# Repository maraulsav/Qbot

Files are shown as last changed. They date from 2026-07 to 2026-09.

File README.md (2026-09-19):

# Qbot-the-self-balancing-robot
Qbot is a self balancing robot that integrate PID mechanism to balances.

The Final Design:


## Key Features
* **ESP32 DevKit C** is the main microcontroller allowing wifi connection for remote controller
* **OLED display 128 x 64 px** for displaying the faces and current state of emotion
* **15 V Lipo Battery** to give power supply
* **MPU 6050** Act as gyroscope and accelerator to measure the degree of robot imbalance
* **Buzzer** to make sounds
* **Button** to regulate the power supply from battery
* **DC DC Buck Converter** to regulate the voltage supply
* **TMC2208 Motor Driver** To help control the wheel motion

## Printed Circuit Board (PCB)
Below is the schematic that I used



Below is the PCB design



And here how to connect the PCB to other component of the robot



**PCB Footprint List**
* 10uF capacitor: Capacitor_THT:CP_Radial_D5.0mm_P2.00mm
* 100uF capacitor: Capacitor_THT:CP_Radial_D6.3mm_P2.50mm
* Zener Diode: Diode_THT:D_DO-35_SOD27_P10.16mm_Horizontal
* LED: LED_THT:LED_D3.0mm
* Mounting Hole: MountingHole:MountingHole_3.2mm_M3
* Connector: Connector_PinHeader_2.54mm:PinHeader_1x04_P2.54mm_Vertical
* Connector 1x02: Connector_AMASS:AMASS_XT30U-M_1x02_P5.0mm_Vertical
* GY521 (MPU6050): GY-521:MODULE_GY-521
* ESP32 DevKit C: Library:MODULE_ESP32-DEVKITC
* TMC2208_SILENTSTEPSTICK:MODULE_TMC2208_SILENTSTEPSTICK

## 3D Design
Note that I would be using 12 cm wheel

Front Side



Right Side



Back Side



## Codes
Code Sample:



## BOM
| Component | Qty | Total (IDR) | Total (USD) | Link |
|---|----:|---:|---:|---|
| Stepper Motor 17HS4401S | 2 | - | $19.08 |[Link](https://www.aliexpress.com/item/1005008098470320.html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) |
| Printed Circuit Board (PCB) | 1 | — | $3.50 | — |
| 2 x Metal 1.9 Beadlock Wheel Rim | 1 | - | $11.12 | [Link](https://www.aliexpress.com/item/1005007014668118.html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) |
| 4pcs 1.9" Wheel Tires (120mm) | 1 | 85,000 | $4.73 | [Link](https://www.aliexpress.com/item/1005005554788142.html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) |
| ESP32-C3 DevKit | 1 | 85,000 | $4.73 | [Link](https://www.tokopedia.com/temins/esp32-nodemcu-esp-32-esp32s-32s-wifi-module-devkit-dev-38-pin-1729797014153692567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) |
| GY-521 MPU-6050 | 1 | 29,500 | $1.64 | [Link](https://www.tokopedia.com/khurs-iot/gy-521-mpu-6050-3-axis-accelerometer-gyroscope-arduino-raspberry-pi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) |
| TMC2208 Motor Driver | 2 | - | $5,82 | [Link](https://www.aliexpress.com/item/1005010480173953.html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) |
| LiPo Battery (11.1V) | 1 | 169,200 | $9.42 | [Link](https://www.tokopedia.com/rin-toys/baterai-lipo-11-1-volt-3s-batre-lithium-polymer-for-wgg-mobil-rc-1734386815592072921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) |
| LiPo Battery Charger | 1 | 65,000 | $3.61 | [Link](https://www.tokopedia.com/rin-toys/charger-baterai-balance-charger-for-2s-3s-7-4v-11-1v-lithium-lipo-battery-1731018524016871129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) |
| Neodymium Magnet | 1 | 20,000 | $1.11 | [Link](https://www.tokopedia.com/tokodstore/magnet-kuat-neodymium-bulat-diy-5-3mm-50pcs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) |
| OLED Display | 2 | 73,000 | $4.09 | [Link](https://www.tokopedia.com/cncstorebandung/oled-display-0-96-inch-i2c-128-64-layar-oled-putih-biru-kuning-biru-untuk-arduino-esp32-dan-proyek-diy-1733644920011851326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)|
| Push Button | 1 | 15,000 | $0.83 | [Link](https://www.tokopedia.com/arduinonano/r16-503bd-4-pin-16mm-push-on-non-locked-button-switch-250v-light-merah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) |
| Jumper Wire (15 cm, 40 pcs) | 1 pack | 23,000 | $1.28 | [Link](https://www.tokopedia.com/arduinonano/kabel-jumper-40p-cable-dupont-pelangi-15cm-40pin-header-cable-pin-rainbow-15-cm-1729801397622441069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) |
| Header Pin | 1 pack | 14,000 | $0.78 | [Link](https://www.tokopedia.com/arduinonano/1x40-pin-2-0mm-male-single-row-header-strip-40-40p-pit-2mm-tulang-ikan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) |
| Heatsink | 2 | 4,656 | $0.26 | [Link](https://www.tokopedia.com/rajacell/heatsink-aluminium-pendingin-14x14x6mm-dengan-3m-thermal-tape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) |
| Heat-Set Inserts | 1 | 252,200 | $14.02 | [Link](https://www.tokopedia.com/smbility/insert-nut-kuningan-hot-500pcs-hot-melt-nutinsert-thread-knurled-spiral-brass-nut-insert-1730606018733835796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) |
| Nut Set | 1 | 131,000 | $7.28 | [Link](https://www.tokopedia.com/fyn-by-finedego/baut-set-m3-m4-m5-m6-600-pcs-hex-ring-mur-screw-bolt-nuts-assortment-kit-stainless-steel-l-bulat-40mm-30mm-20mm-10mm-16mm-1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) |
| 10 µF Capacitor | 1 | 20,400 | $1.14 | [Link](https://www.tokopedia.com/lektropedia/elco-10uf-450v-kapasitor-10-uf-mikro-450-v-volt-elko-450volt-capasitor-1-49-pcs-ed5a8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) |
| 100 µF Capacitor | 3 | 24,900 | $1.16 | [Link](https://www.tokopedia.com/lektropedia/elco-100uf-450v-kapasitor-100-uf-mikro-450-v-volt-elko-450volt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) |
| Zener Diode | 1 | 10,000 | $0.56 | [Link](https://www.tokopedia.com/arduinonano/dioda-zener-1w-3v6-3-6v-1n4729a-in4729a-1n4729-in4729-diode-do-41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) |
| LED | 1 | 1,250 | $0.07 | [Link](https://www.tokopedia.com/arduinonano/led-blink-red-5mm-diode-super-bright-led-kedip-merah-led-5mm-kedip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) |
| 1 kΩ Resistor | 1 | 15,000 | $0.83 | [Link](https://www.tokopedia.com/arduinonano/10pcs-resistor-1k-1-kilo-k-ohm-1-4-watt-0-25-metal-film-tolerance-1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) |
| LM2596S  DC to DC Buck Converter | 1 | 34,200 | $1,92 | [Link](https://www.tokopedia.com/tokoasia-jkt/lm2596s-buck-converter-dc-dc-step-down-voltage-regulator-36v-24v-12v-to-5v-2a-volt-digital-display-2596s-1730718483558664143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) |
| Active Buzzer | 1 | 5,000 | $0.28 | [Link](https://www.tokopedia.com/azzamarduino/buzzer-speaker-aktif-active-dc-3v-24v-sfm-27-3cm-input-3v-5v-12v-bunyi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) |
| XT30 Amass Connector | 1 | 8,500 | $0.47 | [Link](https://www.tokopedia.com/arduinonano/amass-connector-plug-xt30u-amass-xt-30-u-konektor-for-power-1732555087363605613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) |
| 3D Printed Parts | — | — | $9.00 | — |
| **Total** | | **IDR2.049.638** | **USD 115.07** | |

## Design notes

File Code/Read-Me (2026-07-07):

Here contain the code of my Qbot
I use the header and cpp formatting so that the code did not jungle up in one big file. 
If you wanted to use or modify, Download this folder as a zip the open it.
Also download the file that allow MPU6050 to the ESP32C3 in this 
link https://github.com/jrowberg/i2cdevlib (click arduino then MPU6050)

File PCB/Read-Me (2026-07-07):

Here lays the schematic and the pcb layout of my Qbot. 
If you wanted to modify it you can download the .pro file then open it on KiCad.

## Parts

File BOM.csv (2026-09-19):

Name | Qty | Total (IDR) | Total (USD) | Link
Stepper Motor 17HS4401S | 2 |  | 19,08 | https://www.aliexpress.com/item/1005008098470320.html?curPageLogUid=qqeqjQQUr7C6
ESP32C3 DevKit | 1 | 85000 | 4,73 | https://www.tokopedia.com/temins/esp32-nodemcu-esp-32-esp32s-32s-wifi-module-devkit-dev-38-pin-1729797014153692567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
GY-521 MPU-6050 | 1 | 29500 | 1,64 | https://www.tokopedia.com/khurs-iot/gy-521-mpu-6050-3-axis-accelerometer-gyroscope-arduino-raspberry-pi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
LM2596S DC to DC Buck Converter | 1 | 34200 | 1,92 | https://www.tokopedia.com/tokoasia-jkt/lm2596s-buck-converter-dc-dc-step-down-voltage-regulator-36v-24v-12v-to-5v-2a-volt-digital-display-2596s-17307184835586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
Printed Circuit board | 1 |  | 3,5 | JLCPCB
TMC2208 Motor Driver | 2 |  | 5,82 | https://www.aliexpress.com/item/1005010480173953.html?curPageLogUid=mdaYc0tmK80y
Lipobattery 11.1V | 1 | 169200 | 9,42 | https://www.tokopedia.com/rin-toys/baterai-lipo-11-1-volt-3s-batre-lithium-polymer-for-wgg-mobil-rc-1734386815592072921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
LIpobattery charger | 1 | 65000 | 3,61 | https://www.tokopedia.com/rin-toys/charger-baterai-balance-charger-for-2s-3s-7-4v-11-1v-lithium-lipo-battery-1731018524016871129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
Magnet | 1 | 20000 | 1,11 | https://www.tokopedia.com/tokodstore/magnet-kuat-neodymium-bulat-diy-5-3mm-50pcs?t_id=1783211974588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
OLED Display | 2 | 73000 | 4,09 | https://www.tokopedia.com/cncstorebandung/oled-display-0-96-inch-i2c-128-64-layar-oled-putih-biru-kuning-biru-untuk-arduino-esp32-dan-proyek-diy-1733644920011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
Button | 1 | 15000 | 0,83 | https://www.tokopedia.com/arduinonano/r16-503bd-4-pin-16mm-push-on-non-locked-button-switch-250v-light-merah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
Jumper Wire 15 cm | 1 pack | 23000 | 1,28 | https://www.tokopedia.com/arduinonano/kabel-jumper-40p-cable-dupont-pelangi-15cm-40pin-header-cable-pin-rainbow-15-cm-1729801397622441069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
Header Pin | 1 pack | 14000 | 0,78 | https://www.tokopedia.com/arduinonano/1x40-pin-2-0mm-male-single-row-header-strip-40-40p-pit-2mm-tulang-ikan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
Heatsink | 2 | 4656 | 0,26 | https://www.tokopedia.com/rajacell/heatsink-aluminium-pendingin-14x14x6mm-dengan-3m-thermal-tape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
Heatset insert | 1 | 252200 | 14,02 | https://www.tokopedia.com/smbility/insert-nut-kuningan-hot-500pcs-hot-melt-nutinsert-thread-knurled-spiral-brass-nut-insert-1730606018733835796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
Nut set | 1 | 131000 | 7,28 | https://www.tokopedia.com/fyn-by-finedego/baut-set-m3-m4-m5-m6-600-pcs-hex-ring-mur-screw-bolt-nuts-assortment-kit-stainless-steel-l-bulat-40mm-30mm-20mm-10mm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
10 uF capacitor | 1 | 20400 | 1,14 | https://www.tokopedia.com/lektropedia/elco-10uf-450v-kapasitor-10-uf-mikro-450-v-volt-elko-450volt-capasitor-1-49-pcs-ed5a8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
100 uF capcitor (3.5 cm height) | 3 | 24900 | 1,16 | https://www.tokopedia.com/lektropedia/elco-100uf-450v-kapasitor-100-uf-mikro-450-v-volt-elko-450volt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
Zener diode | 1 | 10000 | 0,56 | https://www.tokopedia.com/arduinonano/dioda-zener-1w-3v6-3-6v-1n4729a-in4729a-1n4729-in4729-diode-do-41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
LED | 1 | 1250 | 0,07 | https://www.tokopedia.com/arduinonano/led-blink-red-5mm-diode-super-bright-led-kedip-merah-led-5mm-kedip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
Resistor | 1 | 15000 | 0,83 | https://www.tokopedia.com/arduinonano/10pcs-resistor-1k-1-kilo-k-ohm-1-4-watt-0-25-metal-film-tolerance-1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
Buzzer | 1 | 5000 | 0,28 | https://www.tokopedia.com/azzamarduino/buzzer-speaker-aktif-active-dc-3v-24v-sfm-27-3cm-input-3v-5v-12v-bunyi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
Amass Connector | 1 | 8500 | 0,47 | https://www.tokopedia.com/arduinonano/amass-connector-plug-xt30u-amass-xt-30-u-konektor-for-power-1732555087363605613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
4pcs 1.9" Wheel Tires (120mm) |  | - | 11,07 | https://www.aliexpress.com/item/1005005554788142.html?scm_id=1007.40050.354490.0&scm-url=1007.40050.354490.0
Metal 1.9 Beadlock Wheel Rim |  | - | 11,12 | https://www.aliexpress.com/item/1005007014668118.html?scm_id=1007.40050.354490.0&scm-url=1007.40050.354490.0
3D Print |  |  | 9 | Printing Legion
 | SUM | 2.098.799,74 | 115,07

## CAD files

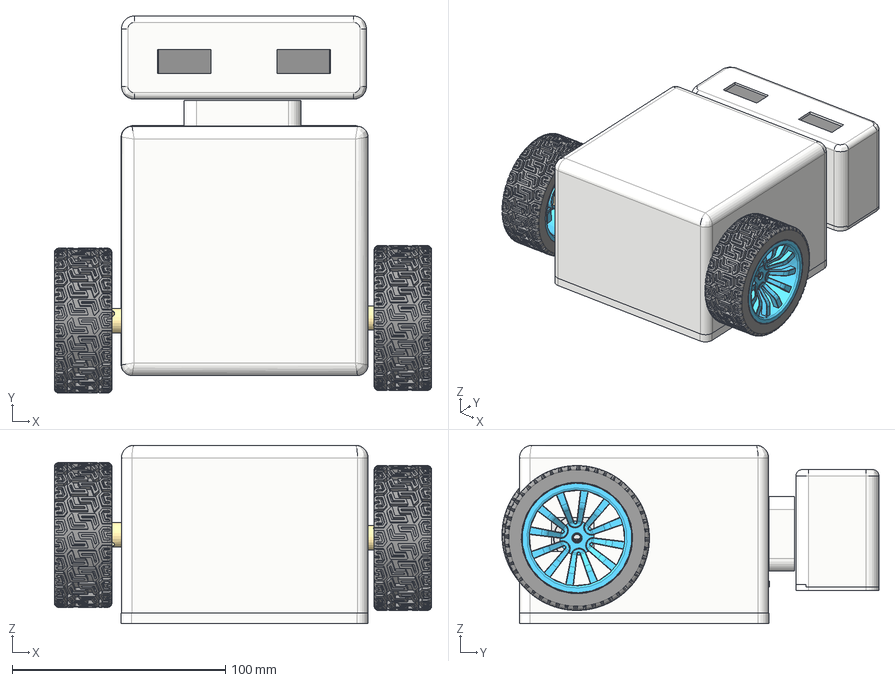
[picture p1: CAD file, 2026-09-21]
3D Print/Qbot (Assembly).step
177.1 x 177.0 x 83.8 mm

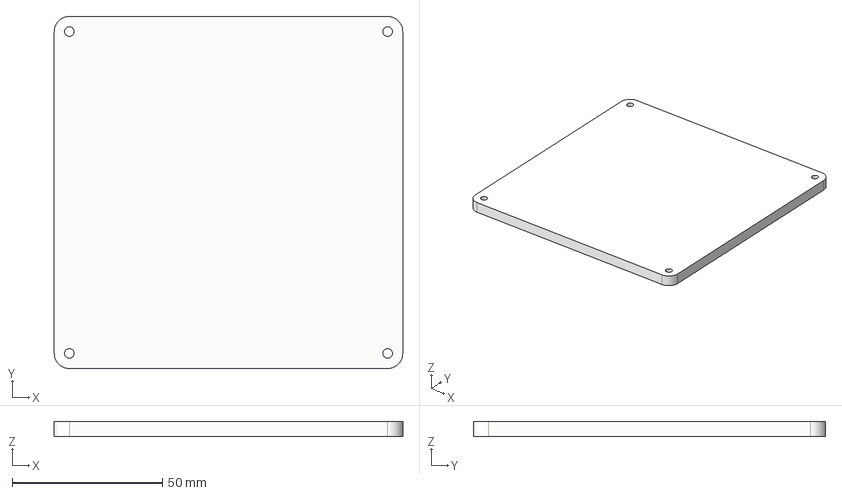
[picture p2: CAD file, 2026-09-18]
3D Print/Body Door.step
115.8 x 117.0 x 5.00 mm

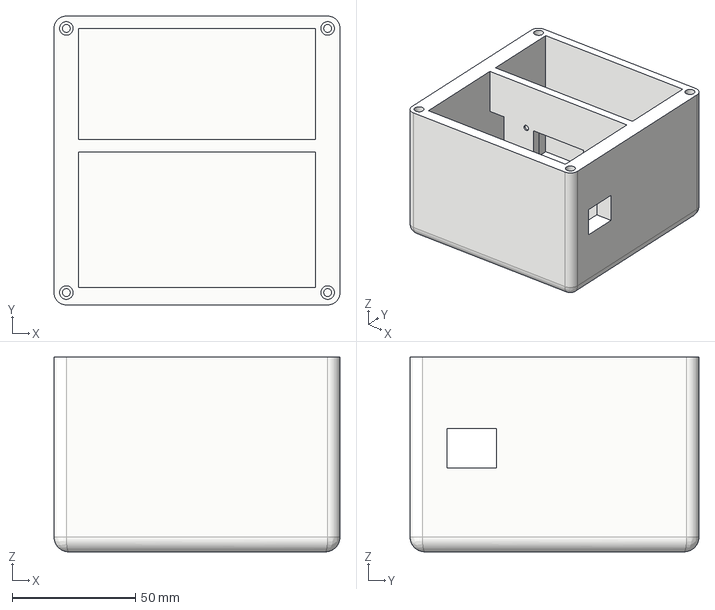
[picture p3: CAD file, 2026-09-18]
3D Print/Body#2.step
115.8 x 117.0 x 78.8 mm

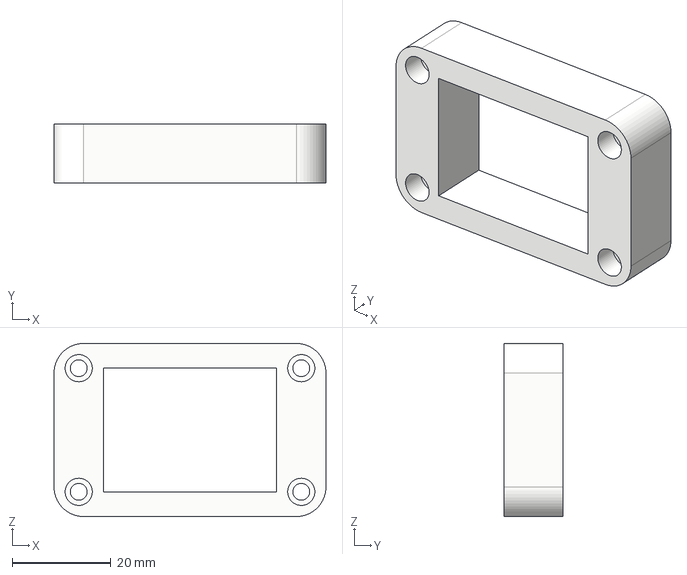
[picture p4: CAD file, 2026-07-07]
3D Print/Neck.step
55.0 x 12.0 x 35.0 mm

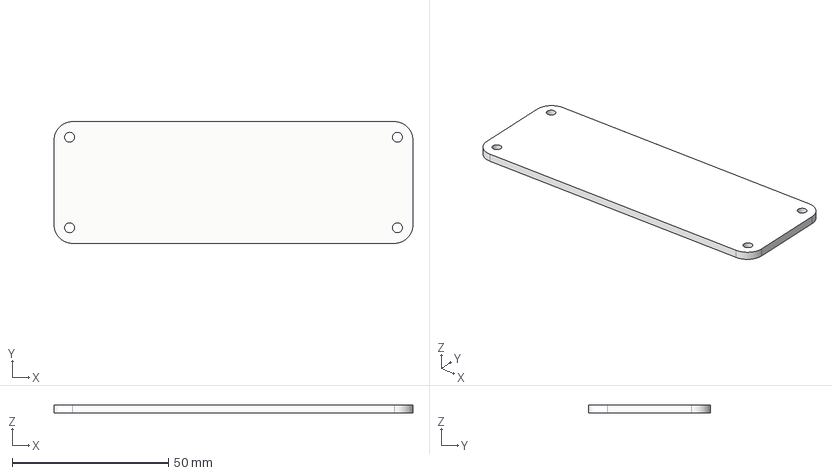
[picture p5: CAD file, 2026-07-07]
3D Print/Head Door.step
115.0 x 39.0 x 2.70 mm

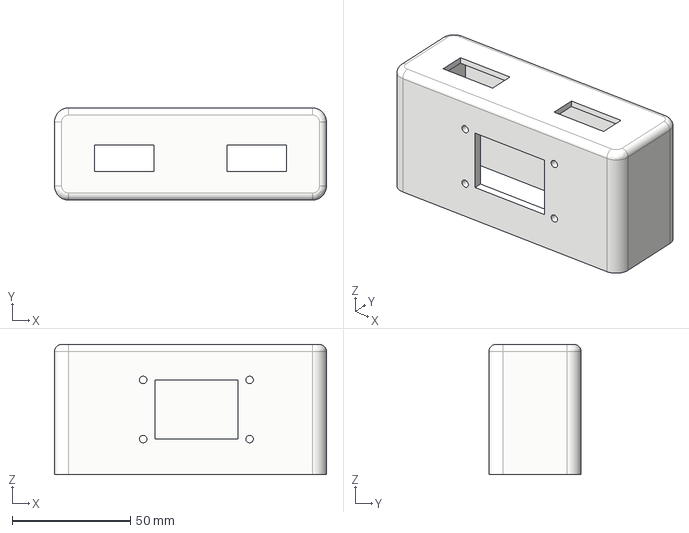
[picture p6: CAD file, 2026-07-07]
3D Print/Qbot Head.step
115.0 x 39.0 x 55.0 mm

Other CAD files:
3D Print/Body Door.f3d
3D Print/Body#2.f3d
3D Print/Head Door.f3d
3D Print/Neck.f3d
3D Print/Qbot Head.f3d

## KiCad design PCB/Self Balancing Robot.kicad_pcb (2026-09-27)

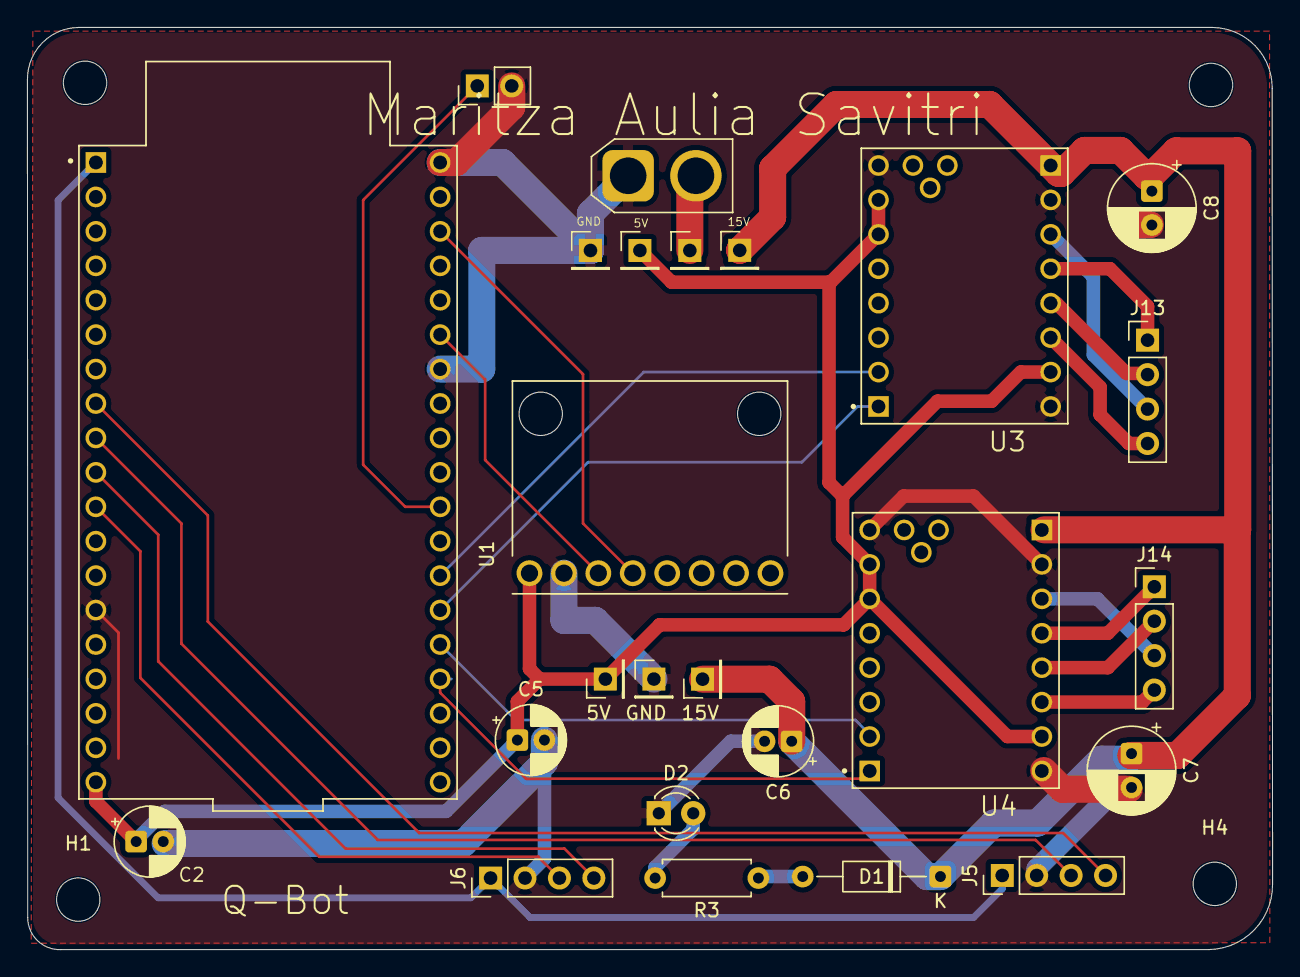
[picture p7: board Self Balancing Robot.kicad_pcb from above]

Board: 2 copper layers, 91.9 x 68.0 mm, 29 parts (0 on the bottom side), 26 nets.

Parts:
5V, 15V: Conn_01x01; PinHeader_1x01_P2.54mm_Vertical
C2, C5, C6: 10uF; CP_Radial_D5.0mm_P2.00mm
C7, C8: 100uF; CP_Radial_D6.3mm_P2.50mm
D1: D_Zener; D_DO-35_SOD27_P10.16mm_Horizontal
D2: LED; LED_D3.0mm
GND: Conn_01x01; PinHeader_1x01_P2.54mm_Vertical
H1, H2, H3, H4: MountingHole; MountingHole_3.2mm_M3
J3: Conn_01x02; AMASS_XT30U-M_1x02_P5.0mm_Vertical
J4: -SW; PinHeader_1x01_P2.54mm_Vertical
J5, J6, J13, J14: Conn_01x04; PinHeader_1x04_P2.54mm_Vertical
J7: +SW; PinHeader_1x01_P2.54mm_Vertical
J8: +SWLED; PinHeader_1x01_P2.54mm_Vertical
J9: -SWLED; PinHeader_1x01_P2.54mm_Vertical
J10: Conn_01x02; PinHeader_1x02_P2.54mm_Vertical
R3: 1k; R_Axial_DIN0207_L6.3mm_D2.5mm_P7.62mm_Horizontal
U1: GY-521; MODULE_GY-521
U2: ESP32-DEVKITC; MODULE_ESP32-DEVKITC
U3, U4: TMC2208_SILENTSTEPSTICK; MODULE_TMC2208_SILENTSTEPSTICK

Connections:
+3V3: J5.1, J6.1, U2.1 (3V3)
+5V: 5V.1 (Pin_1_1), C2.1, C5.1, J8.1 (Pin_1_1), U1.VCC, U2.19 (EXT_5V), U3.JP1_6 (MS2), U3.JP1_7 (MS1), U3.JP2_7 (VIO), U4.JP1_6 (MS2), U4.JP1_7 (MS1), U4.JP2_7 (VIO)
+15V: 15V.1 (Pin_1_1), C6.1, C7.1, C8.1, D1.1 (K), J7.1 (Pin_1_1), U3.JP2_1 (VM), U4.JP2_1 (VM)
/IO17: J10.1, U2.28 (IO17)
/MDDIR1: U2.25 (IO0), U3.JP1_1 (DIR)
/MDDIR2: U2.23 (IO15), U4.JP1_1 (DIR)
/MDSTEP1: U2.26 (IO4), U3.JP1_2 (STEP)
/MDSTEP2: U2.24 (IO2), U4.JP1_2 (STEP)
/SCL: U1.SDA, U2.36 (IO22)
/SCL1: J5.3, U2.9 (IO25)
/SCL2: J6.3, U2.11 (IO27)
/SDA: U1.SCL, U2.33 (IO21)
/SDA1: J5.4, U2.8 (IO33)
/SDA2: J6.4, U2.10 (IO26)
GND: C2.2, C5.2, C6.2, C7.2, C8.2, D2.1 (K), GND.1 (Pin_1_1), J3.1, J5.2, J6.2, J9.1 (Pin_1_1), J10.2, U1.GND, U2.14 (GND1), U2.32 (GND2), U2.38 (GND3), U3.JP1_8 (EN), U3.JP2_2 (GND), U3.JP2_8 (GND), U4.JP1_8 (EN), U4.JP2_2 (GND), U4.JP2_8 (GND)
unnamed: D1.2 (A), R3.1
unnamed: D2.2 (A), R3.2
unnamed: J3.2, J4.1 (Pin_1_1)
unnamed: J13.1, U3.JP2_4 (OA1)
unnamed: J13.2, U3.JP2_5 (OB1)
unnamed: J13.3, U3.JP2_3 (OA2)
unnamed: J13.4, U3.JP2_6 (OB2)
unnamed: J14.1, U4.JP2_4 (OA1)
unnamed: J14.2, U4.JP2_5 (OB1)
unnamed: J14.3, U4.JP2_3 (OA2)
unnamed: J14.4, U4.JP2_6 (OB2)

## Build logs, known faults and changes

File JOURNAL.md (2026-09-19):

---
title: "Qbot the self balancing robot"
author: "Shawnx"
description: "A self  balancing robot.. I want  a robot companion for my mother "
created_at: "2026-06-23"
---

# 2026-09-19: Revision #3 : 3D Design

**Total time spent: 1.5 hours**

Fixing 3D Design!
Hello guys so here I make the body of my self Balancing robot bigger, so that I can fit in the stepper motor and the cables inside.



Oh also some notes  that I search on ali express and I found a wheel that suitable for this, because I thought 6.5 cm would be to small and making the PID hard to tune, I will be using wheel with diameter of 12 cm 

This one: https://www.aliexpress.com/item/1005005554788142.html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

It also minimize the clamping between the body of the robot and the floor

Oh also I have updated my BOM can check on github!
Letsgooo! locked in

# 2026-09-18: Revision #2 PCB FIXED!

**Total time spent: 1.33333 hours**

Hi! PCB  Fixed
Locked innnn!!!!

Schematic

Here I finish up the wiring of the motor driver and also add all the necessary pins for buck to buck converter

PCB also can be recovered

Here I finish up the PCB

# 2026-09-17: Revision #1

**Total time spent: 2 hour**

WOOO I CAME BACKK
Yo, sorry it took so long, I kind of need to prepare my new shool life haha. Yeah adjusting this and there. 
So, this is the first part of the revision
I tried to search more about the component that my reviewer suggest.
Learn the data sheet and also connecting the parts

damn, I think the PCB part is somehow gone, file not found X-X

# 2026-07-08: BOM Making

**Total time spent: 1 hour**

Hey, I list up all the component and the way to get that component.
Also I made an estimate of how much money that people will need to made this project.

Here's what it look like


Here's the time lapse: https://lapse.hackclub.com/timelapse/PPDqvlRXRt7V

# 2026-07-07: Finishing the 3D Design

**Total time spent: 2 hours**

WOHOOOOO!!!
FINALLYY! I finished the Qbot 3D design
Soo, I changed my mind about the magnet because I think magnet might affect the gyroscope, so I think I would use a heeatset insert combined with nails. Also I think that would hold things strongly... Here, I also design the head of the Qbot. I think its cute enough, and proportional welp its more like a chibi but its cute. 



Here is the time lapse:
Time Lapse:  https://lapse.hackclub.com/timelapse/1YpfYYWa6enn

# 2026-07-06: Qbot Body and Neck 3D Design

**Total time spent: 3 hours**

At first I though to connect the body and the door with hinges. But then I thought because I use a 3D print and the the door will be a flying object it would need a lot of support and har to be 3D printed, so I thought to use magnet as a connector



This is the time lapse: https://lapse.hackclub.com/timelapse/bFA7tEurqMoV

# 2026-07-05: Qbot Code Update

**Total time spent: 2 hours**

Hi guys I got to the core of the codes.
Finally, woagh, I understand what I supposed to do (hopefully it works).
I think this instructable article really gave a solid knowledge on how does the PID system works and also to set up the GY521 device
https://www.instructables.com/Arduino-Self-Balancing-Robot-1/



This is the code time lapse:
https://lapse.hackclub.com/timelapse/tOPbFWzLiS3k

# 2026-07-04: Update Schematic and PCB

**Total time spent: 2 hours**

Okay guys so I need to update my schematic and PCB. 

Why I need to update it :
First, The price of IMUBNO055 makes me get a heart attack (jk jk)
but I just know that the price was so high like in my country it is higher than 1/3 my country minimum wage (X-X). Initially when I built this project, I searched up a component that are beginner friendly, and some recommend the BNO055 because it have high accuracy and easy to use, but I don't know the price was really that high.

Second, I forgot that not all esp32 devkit C pins is able to transfer SCL and SDA output. Especially some pins are designated only for input.. So I change that also.

This is the updated schematic:
!

This is the updated PCB:


The time lapse
https://lapse.hackclub.com/timelapse/12TPUjm68HXh

# 2026-07-03: Coding Part 1

**Total time spent: 5.7 hours**

Hello guyss
Just finished coding the display part. I even manage to made my own eyes animation ^^ I use rive for this project. Oh also I found a really good website that can convert your image to cpp: https://javl.github.io/image2cpp/

But I think what's really challenging from this journey is.. understanding HOWW PID WORKSSS WAGGHHH.. Like I know the theory but when I saw like an example of someone else coding part I barely understand anything T-T 

Like I think it really takes alot of time to figure out what happened. This is my first PID project and yeah I still don't really know how everything works and connect to each other. 



I think I will made a part two of my coding journey
Below is the time lapse:
https://lapse.hackclub.com/timelapse/dI2dgVFvJQu4

# 2026-07-01: Wiring Diagram

**Total time spent: 0.2 hours**

Hi! here I made the wiring diagram just incase later people confused on how to connect the PCB to other components. Its also made me easier to determine which things I need to buy



# 2026-07-01: Design the PCB 

**Total time spent: 1.7 hours**

Hi guyss I am finishing my PCB Design. Here's my final result


I think PCB design was the most exciting part when I built a project because it feels like connecting puzzle. 

Oh and also few decision making from me is that
I use 2 milimiter trace for the 15V and some of the GND to reduce voltage drop and also allowing higher current carrying capacity. Also I did a ground pour because I wanted to improve the heat dissipation. As I used large voltage I think heat would be one of problem that I should manage.

Oh and I also keep the ESP32C3 usb place clear so that I can plug my cable thereee. 

I think what I would recommend when doing a PCB tracking is that you have to some short of imagining how the whole product gonna look and also saw your schematic so you have a good reference

Here's the time lapse
https://lapse.hackclub.com/timelapse/fii9hiq6UW8N

# 2026-06-30: Schematic Design

**Total time spent: 4.5 hours**

Hi! I have finished my schematic design. Below is the picture of it



So, how did I made the schematic design.
First of all, I watched other people design self-balancing robots. here's what I recommend to watch, they made good documentation too
1. https://www.youtube.com/watch?v=J5Xd43LIFiU
2. https://www.instructables.com/Arduino-Self-Balancing-Robot-1/

Then I observed their schematics and tried to understand each component and how can they work and influence each other. Then, I proceed to made my own schematic, I check the availability of the components in my country. and also for making the PCB I only use the through hole component, because SMD is really hardd to solder. 

Oh also then you need to search for the suitable footprint

I think the most challenging part to make this schematic design is searching for the component that are available and making sure that they compatible and suitable for the project that I used.

A few decision making
I decide to use two oled display for the eyes of the robot because I think if I used only one the eyes would be really small and if I use the circular OLED display (I am planning to use 2 display) it used seven pins each so I think its kind of overkill.

The timelapse: https://lapse.hackclub.com/timelapse/6rL22KKTCqLC 
Oh btw sorry at some part I forgot to turn off the timelapse when put my mac on sleep. I have cut the blank part in my time submission here

# 2026-06-25: Ideas

**Total time spent: 0.5 hours**

I think this robot will be a lot like the Wall-E robot. WAGHH SO CUTEEE.
Well, I have made like how is it going to look like in Canva.



( I dont know why I have difficuty on uploading image, like I need to upload it to another program journal then copy the code to this)

I think I am gonna make like 3 layers 
The bottom one is for the motor driver and the wheel..
Then the second layer is for the microcontroller thingy and the IMU BNO055 sensor for balancing
And the third layer is for the bateries and the OLED Display I still cant decide which better using two circle oled display or just one rectangle oled display, I think I still need to think about it

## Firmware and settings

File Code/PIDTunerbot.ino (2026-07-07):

// SBR.ino
#include <Arduino.h>
#include "motor.h"
#include "espnow.h"
#include "display.h"
#include <Wire.h>
#include <Adafruit_Sensor.h>
#include <Adafruit_BNO055.h>

#include "I2Cdev.h"
#include "MPU6050.h"
#include "math.h"

//MPU6050 variables
MPU6050 mpu;
int16_t gyroX, gyroRate;
float gyroAngle=0;
unsigned long currTime, prevTime=0, loopTime;

void mpuWriteReg(uint8_t reg, uint8_t val) {
  Wire.beginTransmission(MPU_ADDR);
  Wire.write(reg);
  Wire.write(val);
  Wire.endTransmission();
}

void mpuInit() {
  Wire.begin(SDA_PIN, SCL_PIN);
  Wire.setClock(400000);
  mpuWriteReg(0x6B, 0x00);
  delay(100);
  mpuWriteReg(0x1B, 0x00); 
  mpuWriteReg(0x1C, 0x00); 
}

void mpuReadRaw() {
  Wire.beginTransmission(MPU_ADDR);
  Wire.write(0x3D); 
  Wire.endTransmission(false);
  Wire.requestFrom((int)MPU_ADDR, 8, true); 

  accY_raw  = (Wire.read() << 8) | Wire.read();
  accZ_raw  = (Wire.read() << 8) | Wire.read();
  Wire.read(); Wire.read(); // discard temperature
  int16_t gx = (Wire.read() << 8) | Wire.read();
  gyroX_raw = gx;
}

// PID control variables
double setpoint = 3;  // Desired angle (upright position)
double input = 0.0;   // Current angle from IMU
double output = 0.0;  // PID controller output

// PID tuning parameters (to be adjusted via ESP-NOW)
double Kp = 20.0;
double Ki = 0.0;
double Kd = 0.3;

// PID calculation variables
double previousError = 0.0;
double integral = 0.0;
unsigned long lastComputeTime = 0;

void setup() {
  // Initialize serial communication
  Serial.begin(115200);
  while (!Serial) {
    delay(10);  // Wait for Serial to initialize
  }

  // Initialize the MPU 6050 sensor
  if (mpu.initialize()) {
    Serial.println("Error initializing MPU6050! Check your connections.");
    while (1)
      ;
  }

  delay(2000);  // Allow sensor initialization
  Serial.println("MPU6050 sensor initialized successfully!");
  // Initialize motor
  motorSetup();
  // Initialize last compute time
  lastComputeTime = millis();
  // Initialize ESP-NOW
  espnowSetup();
  displaySetup();
}

void loop() {
  // Read sensor data every 10ms
  static unsigned long lastSensorReadTime = 0;
  accY = mpu.getAccelerationY();
  accZ = mpu.getAccelerationZ();  
  gyroX = mpu.getRotationX();

  if (millis() - lastSensorReadTime >= 10) {

    // Get orientation data from IMU
    accAngle = atan2(accY, accZ)*RAD_TO_DEG;
    gyroRate = map(gyroX, -32768, 32767, -250, 250);
    gyroAngle = (float)gyroRate*sampleTime;  
    orientationData = 0.9934*(prevAngle + gyroAngle) + 0.0066*(accAngle);
  
    error = currentAngle - targetAngle;
    errorSum = errorSum + error;  
    errorSum = constrain(errorSum, -300, 300);


    // Extract the pitch angle (assuming orientation.z is pitch)
    input = orientationData.orientation.z;

    // Compute PID output
    computePID();

    // Update motor control based on PID output
    updateMotorControl(output);

    // Send PID data via ESP-NOW
    sendPIDData();

    // Debugging output (optional)
    Serial.print("Setpoint:");
    Serial.print(setpoint);
    Serial.print(",");
    Serial.print("Pitch:");
    Serial.print(input);
    Serial.print(",");
    Serial.print("PID Output:");
    Serial.println(output);
  }

  // Generate step pulses
  generateStepPulses();
}

void computePID() {
  unsigned long currentTime = millis();
  double dt = (currentTime - lastComputeTime) / 1000.0;  // Convert to seconds
  lastComputeTime = currentTime;

  // Avoid division by zero
  if (dt <= 0)
    dt = 0.001;

  // Calculate error
  //double error = setpoint - input;

  // Calculate integral
  //integral += error * dt;
  integral += errorsum * dt

  // Apply integral windup protection
  if (integral > 3) {
    integral = 3;
  }
  if (integral < -3) {
    integral = -3;
  }

  // Calculate derivative
  double derivative = (error - previousError) / dt;

  // Compute PID output
  output = Kp * error + Ki * integral + Kd * derivative;

  // Save error for next loop
  previousError = error;

  // Constrain output
  if (output > 255) {
    output = 255;
  }
  if (output < -255) {
    output = -255;
  }

  // Populate pidData for sending
  pidData.p = Kp * error;
  pidData.i = Ki * integral;
  pidData.d = Kd * derivative;
  pidData.setpoint = setpoint;
  pidData.input = input;
  pidData.output = output;

  // Debugging output (optional)
  Serial.print("P:");
  Serial.print(pidData.p);
  Serial.print(",");
  Serial.print("I:");
  Serial.print(pidData.i);
  Serial.print(",");
  Serial.print("D:");
  Serial.print(pidData.d);
  Serial.print(",");
}

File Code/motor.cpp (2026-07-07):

#include "motor.h"

// Define pin connections for Motor 1
const int dirPin1 = 15;
const int stepPin1 = 2;

// Define pin connections for Motor 2
const int dirPin2 = 0;
const int stepPin2 = 4;

// Motor control variables
unsigned long lastStepTime = 0;
double stepDelayUs = 1000;  // Initial delay between steps in microseconds
int motorDir = HIGH;        // Initial motor direction

void motorSetup() {
  // Initialize the output pins for Motor 1
  pinMode(dirPin1, OUTPUT);
  pinMode(stepPin1, OUTPUT);

  // Initialize the output pins for Motor 2
  pinMode(dirPin2, OUTPUT);
  pinMode(stepPin2, OUTPUT);

  // Initialize motor direction
  digitalWrite(dirPin1, motorDir);
  digitalWrite(dirPin2, !motorDir);  // Inverse of motorDir
}

void generateStepPulses() {
  unsigned long now = micros();
  if (now - lastStepTime >= stepDelayUs) {
    lastStepTime = now;

    // Generate a step pulse
    digitalWrite(stepPin1, HIGH);
    digitalWrite(stepPin2, HIGH);
    delayMicroseconds(2);  // Pulse width
    digitalWrite(stepPin1, LOW);
    digitalWrite(stepPin2, LOW);
  }
}

void updateMotorControl(double pidOutput) {
  // Determine motor direction based on PID output
  if (pidOutput > 0) {
    motorDir = HIGH;  // Motor 1 forward, Motor 2 backward
  } else {
    motorDir = LOW;          // Motor 1 backward, Motor 2 forward
    pidOutput = -pidOutput;  // Use absolute value for speed
  }

  // Set motor directions (inverse of each other)
  digitalWrite(dirPin1, motorDir);
  digitalWrite(dirPin2, !motorDir);  // Inverse direction

  // Map PID output to steps per second (motor speed)
  const double MaxPIDOutput = 255.0;        // Maximum PID output
  const double MaxStepsPerSecond = 8000.0;  // Maximum motor speed
  const double MinStepsPerSecond = 0.0;     // Minimum motor speed

  // Constrain PID output
  if (pidOutput > MaxPIDOutput)
    pidOutput = MaxPIDOutput;

  // Map PID output to motor speed
  double stepsPerSecond = mapDouble(pidOutput, 0.0, MaxPIDOutput, MinStepsPerSecond, MaxStepsPerSecond);

  // Prevent division by zero
  if (stepsPerSecond < 1)
    stepsPerSecond = 1;

  // Calculate delay between steps in microseconds
  stepDelayUs = 1e6 / stepsPerSecond;
}

double mapDouble(double x, double in_min, double in_max, double out_min, double out_max) {
  return (x - in_min) * (out_max - out_min) / (in_max - in_min) + out_min;
}

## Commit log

2026-09-19 Update components in README and adjust BOM
2026-09-19 Update BOM
